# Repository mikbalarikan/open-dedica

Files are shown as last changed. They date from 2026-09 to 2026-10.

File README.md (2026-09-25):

# Open Dedica — open-source DIY espresso machine

A community-built espresso machine: **genuine De'Longhi Dedica EC685 internals** (ULKA pump, 1300 W thermoblock, 51 mm portafilter, OEM valves and tubes) inside a **fully open, 3D-printable chassis**.

The only part of a Dedica you cannot buy as a spare is the group-head housing, which is molded into the case. If that part must be printed anyway, the whole chassis can be an open design.

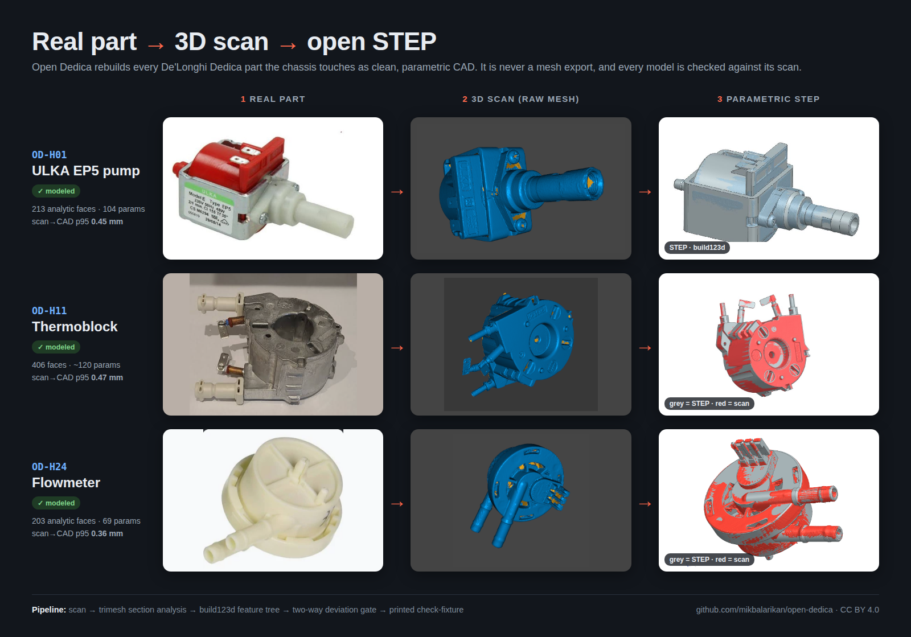
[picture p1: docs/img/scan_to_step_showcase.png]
Real part → 3D scan → open STEP


> ⚠️ **Safety:** this machine runs on mains voltage (230 V / 120 V), heats water to ~125 °C and pressurizes it to 15 bar. Keep the wet side separated from the electric side, keep the 192 °C thermal cutoff (TCO) in circuit, test behind an RCD/GFCI, and never print load-bearing or heat-adjacent parts in PLA.

## How it works

Water path schematic

Tank → flowmeter → ULKA pump → 3-way valve (bypass back to tank) → thermoblock → 3-way connector → group head. The steam branch is phase 2. Details: [docs/WATER_FLOW.md](docs/WATER_FLOW.md).

## Roadmap

| Phase | Goal | Tracking |
|---|---|---|
| **1. 3D scanning** ← *we are here* | Photos + caliper sheet + raw STL for every part the chassis touches | [`phase: scan`](../../issues?q=is%3Aissue+label%3A%22phase%3A+scan%22) |
| 2. STEP library | Rebuild each scan as clean parametric CAD, validate with a printed check-fixture | `phase: step` |
| 3. Chassis | Two-zone printed chassis designed around the STEP assembly; group-head housing first | `phase: chassis` |
| 4. Electronics | OEM PCB (path 1) vs ESP32 + SSR open controller (path 2) | `phase: electronics` |
| 5. Test & release | Pressure / leak / PAT tests, BOM + STEP + STL/3MF + build guide | `phase: test` |

**Scan → STEP progress** (auto-generated from the BOM, details in [docs/STEP_PROGRESS.md](docs/STEP_PROGRESS.md)):

Scan to STEP progress

**Milestone 1:** donor machine torn down, every part catalogued against the BOM, STEP library validated with printed check-fixtures, printed group-head housing bench-tested under pressure.

## How to help

Nobody is pre-assigned — **pick any open issue**. Start with [`good first issue`](../../issues?q=is%3Aissue+is%3Aopen+label%3A%22good+first+issue%22) or the scan requests. Read [CONTRIBUTING.md](CONTRIBUTING.md) first.

## Repository layout

```
docs/          SOURCING_GUIDE.md, BOM.md (generated) + bom.csv (source), PART_NUMBERING.md, WATER_FLOW.md, STEP_PROGRESS.md
tools/         build_bom.py — regenerates docs/BOM.md from docs/bom.csv
scans/         OD-Xnn_<name>/  photos/, calipers.md, raw STL/PLY   (phase 1)
step/          OD-Xnn_<name>.step  clean parametric models          (phase 2)
chassis/       printed chassis CAD + STL/3MF exports                     (phase 3)
electronics/   wiring, pinouts, firmware                                  (phase 4)
```

## Credits & references

- Zack Moss, *Open Source Espresso Machine for Makers*, MEng thesis, University of Sheffield, 2019 — reverse-engineered the EC685.M and proved the concept.
- [CaiJonas Dedica EC685/EC885 mod](https://github.com/CaiJonas/DeLonghi-Dedica-EC885-EC685-modification) — pressure/temperature sensor mod.
- Part codes: De'Longhi EC885.M exploded view (not redistributed here).

This project is not affiliated with or endorsed by De'Longhi. "De'Longhi" and "Dedica" are trademarks of their owners.

## License

Designs and documentation: [CC BY 4.0](LICENSE).

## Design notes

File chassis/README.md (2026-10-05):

# chassis/ — the printed parts and the assembly

Printed chassis CAD and STL/3MF exports (phase 3), designed part by part with the
OGUZ Atölye pipeline (`mikbalarikan/oguz-atolye`); each part's job record sits in
`reports/<part>/` with a README that says how to resume it.

## Goal

Every custom part of the machine that is 3D-printable, designed and reviewed, and
the whole machine delivered as an assembly:

- one parametric build script, STEP (mm, one named solid) and STL/3MF per printed
  part, with its print orientation and material stated;
- the top assembly `OD-000` as a STEP that places every printed part and every OEM
  part of the `step/` library by joints, with the sub-assemblies `OD-H00`, `OD-G00`,
  `OD-W00`, `OD-E00`, `OD-C00`;
- `docs/bom.csv` at `modeled` for every part, `docs/BOM.md` and the progress board
  regenerated, and a build guide (`docs/BUILD_GUIDE.md`) that goes from the BOM to a
  running machine.

`validated` needs a print and a fit check by the Usta; the group head also needs the
bench pressure test (`OD-T01`).

## Order of work

Each part is designed against the scanned OEM parts it touches. A part whose OEM
neighbour is not scanned yet carries that neighbour as an assumption row and is
revisited when the scan lands.

| # | Part | Designed against | Blocked by |
|---|---|---|---|
| 1 | `OD-G01` group head housing | OD-G09, OD-G04, OD-G10 | modeled, RV01 REVISE on REQ-12 alone (brew-load strength, answered only by the OD-T01 bench test), accepted by the Usta as a documented deviation (2026-10-02); every geometric row passes |
| 2 | `OD-C05` group head carrier | OD-G01's rear flange, OD-H11 outlet side | modeled, RV02 approved on assumptions (ASA, K1C); open: drain for the foot trough, counterbore floors to sign, a ≥ 210 mm driver |
| 3 | `OD-C03` pump cradle | OD-H01; sleeve OD-H02 and spring OD-H03 | modeled, approved on assumptions (RV02); calipers: H02 sleeve OD, side-wall gap, tie path |
| 4 | `OD-C04` thermoblock mount | OD-H11 with its NTC/TCO brackets (OD-H17, H19) | modeled, approved on assumptions (RV01); calipers: 10.10 mm air gap, spacer lengths, bracket holes |
| 5 | `OD-C07` valve and flowmeter mount | OD-H22, OD-H24 (OD-H21 sits in the water path, not on the mount) | modeled; RV01 REVISE, two seat gaps accepted by the Usta as deviations |
| 6 | `OD-C06` water tank dock | OD-W03 seat; tank OD-W01/W02 | deferred: the tank stands on the table (the Usta, 2026-10-01); its tubes and the mains cord leave through OD-C11's three Ø12 pass-throughs at y 30 |
| 7 | `OD-C01` base frame / floor plate | the footprints of 2–6; drip tray OD-C21/C22 | modeled, revision B: RV02 approved on assumptions (PLA for now, Kobra Max 3), 38 insert holes; flatness is a bench check; layout assumes the group head vertical, housing rear face 205 mm above the base (awaits the Usta's axis decision); OD-C01 A-12 (feet screwed from below) is superseded by OD-C15 A-02 (screw from above, captive nut); revision B (spec 1.3, build v03, RV02 approved on assumptions) adds the 18 holes for OD-C08, OD-C11, OD-C16 and OD-C09 |
| 8 | `OD-C02` wet/electric bulkhead | OD-C01, the tube runs | modeled, RV01 approved on assumptions (ASA, K1C); M3×12 into the base rail (`OD-F10`) |
| 9 | `OD-C08` electronics bay tray | OD-E01, OD-E02 (path 1) or OD-E51…E58 (path 2) | modeled, RV01 approved on assumptions (PETG, K1C); path 1, the OEM PCB OD-E01 on edge; OD-E02 (front buttons) belongs to OD-C09 |
| 10 | `OD-C09` front panel with button bezel | OD-G01 mouth, OD-E02 buttons, OD-S03 knob (phase 2) | modeled, RV01 approved on assumptions (PLA, Kobra Max 3): 3.0 fascia at z +94 … +97 with return ribs round the brew opening, two floor flanges into four OD-C01 inserts, OD-E02 on two Ø11 bosses (buttons in a column on the left pillar); the locked portafilter swings φ −55 … +10 with ≥ 2.5 to the window edge; the phase-2 steam knob place stays free |
| 11 | `OD-C10`, `OD-C11` top and back panels | OD-C01, OD-C02 | modeled, both RV01 approved on assumptions (PETG, Kobra Max 3); OD-C11 took three builds (spec faults in 1.0 and 1.1, recorded) |
| 12 | `OD-C12`, `OD-C13` side panels; `OD-C16` corner brackets | OD-C01 | modeled, RV01 approved on assumptions (PLA, printed not acrylic): 3.0 plates 385 × 218.8 on the Kobra Max 3 with a 60° lip that locates the lid skirt (0.40 per side); OD-C12 has a 0.9 relief over OD-C07; six 19 × 16 × 16 brackets (three per side), one M3 down into OD-C01 and one insert for the panel screw; the lid now rests on the panel tops (answers OD-C10 F1) |
| 13 | `OD-C14` cable grommets, `OD-C15` feet (TPU) | OD-C01, OD-E06 cord | `OD-C15` modeled, RV01 approved on assumptions: Ø18 × 10 puck, M3×12 from the top into a captive M3 nut; `OD-C14` modeled, RV01 approved on assumptions: two identical PLA halves around the Ø7.0 cord (the Usta's calipers), closed by one `OD-F09` tie inside OD-C11's wall |
| 14 | `OD-T01` group head pressure-test rig | OD-G01, OD-G10 | modeled, v02 (25 mm plate, the Usta's decision on RV01 F1), RV02 approved on assumptions: a closed PLA frame 240 × 160 × 120 that holds OD-G01 mouth down by its four inserts; procedure `OD-T01_TEST_PROCEDURE.md` (100 % infill, watch the screw heads) closes OD-G01 REQ-12 on the bench |
| 15 | `OD-C00` … `OD-000` assemblies | everything above plus the `step/` library | all parts |

**Material for now:** the Usta set PLA for every printed part (2026-10-02); the BOM
keeps each part's service material next to it. PLA softens near 60 °C, so PLA
prints of `OD-G01`, `OD-C02`, `OD-C04` and `OD-C05` (next to the thermoblock and the
group head; OD-C02 stands 13 from the casting) are dry fit checks only: never run hot water or pressure through them, and
run the OD-T01 bench test on an ASA housing.

Machine profiles: Creality K1C (enclosed: ASA, PC) and Anycubic Kobra Max 3 (large
panels: PETG); build volumes to be read into `oguz-atolye/atolye/machines/`.

## Interfaces to OD-C01

Parts that bolt to the base frame fix it with M3 screws into heat-set inserts
(`OD-F01`) in `OD-C01`. Coordinates are in each part's own frame, from its job
record; OD-C01 must carry an insert at each.

| Part | Inserts in OD-C01 (x, z) mm | Hardware |
|---|---|---|
| `OD-C03` pump cradle | (±34, −4), (±34, 37) | 4 × M3 (`OD-F02`), 2 × cable tie (`OD-F09`) |
| `OD-C04` thermoblock mount | (±40, −8), (±40, 26) | 4 × M3 (`OD-F02`); the thermoblock sits on the metal spacers `OD-F07` and `OD-F08` (a Ø3.5 self-tapping screw (`OD-F16`) through each Ø4 bore into the thermoblock, S1 ≈ 22 and S2 ≈ 50 long (OD-C04 A-04)) |
| `OD-C07` valve and flowmeter mount | four Ø3.4 through-holes at (−18, ±21) and (88.5, ±21) in the mount frame; OD-C01 spec 1.1 REQ-10 provides them | 4 × M3 (`OD-F02`) into OD-C01; 2 × M3 insert (`OD-F01`) for OD-H22 |
| `OD-C08` electronics bay tray | flange (88, −222), (106, −222), (88, −78), (106, −78) | 4 × M3×8 (`OD-F02`); 2 × M3×6 (`OD-F11`) for the board into 2 inserts in the tray's standoffs |
| `OD-C11` back panel | flanges (±81, −282), (±95, −282) | 4 × M3×8 (`OD-F02`); 2 inserts in its ledge take OD-C10's rear screws |
| `OD-C10` top panel | none: 2 screws into OD-C02's top-rail inserts, 2 into OD-C11's ledge | 4 × M3×8 (`OD-F02`) |
| `OD-C16` side-panel brackets | (±104.5, −262), (±104.5, −15), (±104.5, +62) | 6 × M3×8 (`OD-F02`) down into OD-C01, 6 more through the panels into the brackets' inserts |
| `OD-C09` front panel | (±85, +77), (±95, +77) | 4 × M3×8 (`OD-F02`); OD-E02 on 2 × M3×18 (`OD-F13`) into 2 inserts in the panel's bosses |
| `OD-C15` feet | none: the four Ø3.4 through-holes at (±110, +90) and (±110, −295) | 4 × M3×12 (`OD-F10`) from the plate top, 4 × M3 nut (`OD-F12`) captive in the feet |

Insert pattern as built into OD-C01 (OD-C01 frame, x and z in mm):

| Part | x | z |
|---|---|---|
| `OD-C05` | ±35 | −40, −60 |
| `OD-C04` | ±40 | −148, −114 |
| `OD-C03` | −4, 37 | −239, −171 |
| `OD-C02` | 65 | −45, −105, −165, −225 |
| `OD-C07` | −113, −71 | −42, −148.5 |
| `OD-C08` | 88, 106 | −222, −78 |
| `OD-C11` | ±81, ±95 | −282 |
| `OD-C16` | ±104.5 | −262, −15, +62 |
| `OD-C09` | ±85, ±95 | +77 |

Revision B's eighteen holes are Ø4.0 through the 6.0 plate like the other twenty, inserts driven from the top (OD-C01 spec 1.3, A-11); RV02 measured each ≥ 10.0 centre to centre from every other hole and ≥ 10.0 from the plate's outline. The four holes at x 65 stay empty: OD-C02's M3×12 pass through them from below into the bulkhead's rail.

Frames for OD-000: OD-C01, OD-C02, OD-C08, OD-C10, OD-C11 and OD-C07's footprint use the machine frame (X right, +Y up, +Z front, plate top y = 0); OD-C05 is in the housing frame (x → X, y → +Z, z → −Y, origin (0, 180.06, 32.0)). Check every insert pattern with calipers before the first print.

OD-000 placements handed over by the part jobs (joint frames; the assembly uses them):

- `OD-C07`: OD-H24 at (0, 0, 10) and OD-H22 at (62, 0, 48) in the mount frame; the mount sits on OD-C01 with mount x → −Z, y → −X, z → +Y, origin (−92, 0, −60) in the OD-C01 frame.
- `OD-C08`, `OD-C10`, `OD-C11`: modelled in the machine frame, placed at the identity. OD-E01 sits on OD-C08 with board x → −Z, y → +Y, z → +X, origin (84, 80, −100). Check assemblies: `reports/<part>/02_STEP_STL/`.
- `OD-C15`: foot frame origin at the centre of its top face, foot z 0 … 10; foot x → X, y → +Z, z → −Y, origins (±110, −6, +90) and (±110, −6, −295). The counter is at y −16. Check assembly: `reports/OD-C15_foot/02_STEP_STL/od_c15_assembly_C1_v01.step`.
- `OD-C12`, `OD-C13`: identity; outer faces at x ±120, z −295 … +90, wall y 0 … 215, lip apex y 218.81.
- `OD-C16` (its frame: block x −19 … 0, y 0 … 16, z ±8): right side translate (117, 0, z_c); left side rotate 180° about Y, then translate (−117, 0, z_c); z_c ∈ {−262, −15, +62}.
- `OD-C14` half: identity; the second half is the same solid rotated 180° about the line through (x 95, y 30) along Z; flange on OD-C11's outer face (z −304 … −302).
- `OD-C09`: identity. OD-E02 on it: board x → −Y, y → −X, z → −Z, origin (−99.0, 140.0, 69.35); its two M3×18 from the board's back into the bosses. OD-T01 is a bench fixture, not in OD-000.
- `OD-G01`: the group head stands with its axis vertical and the mouth down (the spec §2 sentence saying +Z is horizontal is being corrected in spec 1.4).

Keep-outs for later parts:

- `OD-C15` (spec A-09): a Ø8 × 2.0 cylinder above each foot hole on the plate top (y 0 … 2.0) holds the screw head. OD-C11's wall foot clears it by 0.0 (touching, no overlap); OD-C12, OD-C13 and OD-C16 leave it free (side REQ-07); OD-C06 must too.
- `OD-C08` occupies x 73 … 112, z −230 … −70, y 0 … 92 (with the board, to x ≈ 109.3).
- Front corners: OD-C09's wall ends at x ±116 and the side panels at z +90, so about 4 stays open at each front R 10 corner, closed above by OD-C10's skirt; a small corner cap (or OD-C16 at the front corners) can close it. OD-E02 reaches x −115.17, 1.83 inside the left panel. OD-C10's front skirt rests on OD-C09's top edge (y 215), no screws at the front.
- OD-C09 keeps free: the phase-2 steam knob place (Ø32 about x +95.5, y 140, z +60 … +93.8) and the drip tray slot x ±74.8, y 0 … 49.8, z −15 … +120.
- Assembly order (OD-C09 A-14): screw OD-C09 to the plate before OD-E02 goes on; drive the board's two screws from behind with the lid off.
- Rear corners: a ≈ 4 × 4 opening stays between each side panel's end and OD-C11's wall over the plate's corner, closed above by the lid; a small printed cap can close it later.
- The cord grommet's tie head points up inside OD-C11's wall: nothing within 0.5 of it.

"Approved on assumptions" (`APPROVED_ASSUMPTION_CONDITIONAL`) means every gate
passes on scan-derived values that the Usta has not confirmed with calipers yet;
the BOM shows such parts as `modeled`, and `validated` still needs the print and
fit check.

## Files

```
chassis/
  OD-Cnn_<short_name>.step  .stl  .3mf     one per printed part (OD-G01 too)
  OD-000_open_dedica_assembly.step         the top assembly, sub-assemblies inside
  src/OD-Xnn_<short_name>/build_*.py       parametric build and check scripts
  reports/OD-Xnn_<short_name>/             the job record of each part
```

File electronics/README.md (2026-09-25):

# electronics/

Wiring diagrams, OEM PCB pinouts, open-controller firmware (phase 4).

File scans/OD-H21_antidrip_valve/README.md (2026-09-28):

# OD-H21_antidrip_valve — Anti-drip valve

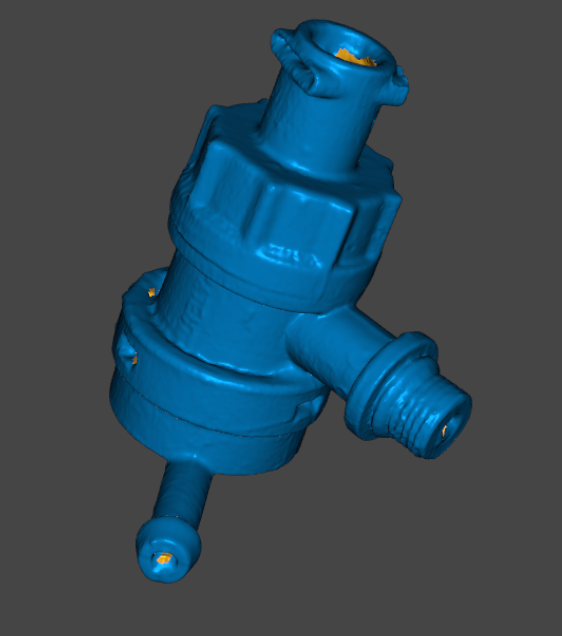
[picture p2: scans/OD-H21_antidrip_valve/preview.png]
scan preview


| | |
|---|---|
| Part | `OD-H21` (ref 39, OEM 7313260161) — see [docs/BOM.md](../../docs/BOM.md) |
| Mesh | `OD-H21_antidrip_valve_raw.stl` — binary STL, **mm**, full resolution, not watertight |
| Scanner | CR-Scan Raptor, 3 merged scan session(s) |
| Date | 2026-09-25 (scan), 2026-09-28 (STEP) |

STEP rebuild: [`step/OD-H21_antidrip_valve.step`](../../step/OD-H21_antidrip_valve.step) — report in [`step/reports/OD-H21_antidrip_valve/`](../../step/reports/OD-H21_antidrip_valve/). Tracked in #41.

## Still missing for this scan
- [ ] `photos/` — own photos with a ruler (the RE run used catalogue images, which we can't publish)
- [ ] `calipers.md` — interface dimensions (the mesh is for the envelope only; calipers win on every fit)

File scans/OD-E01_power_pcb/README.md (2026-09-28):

# OD-E01_power_pcb — Power PCB

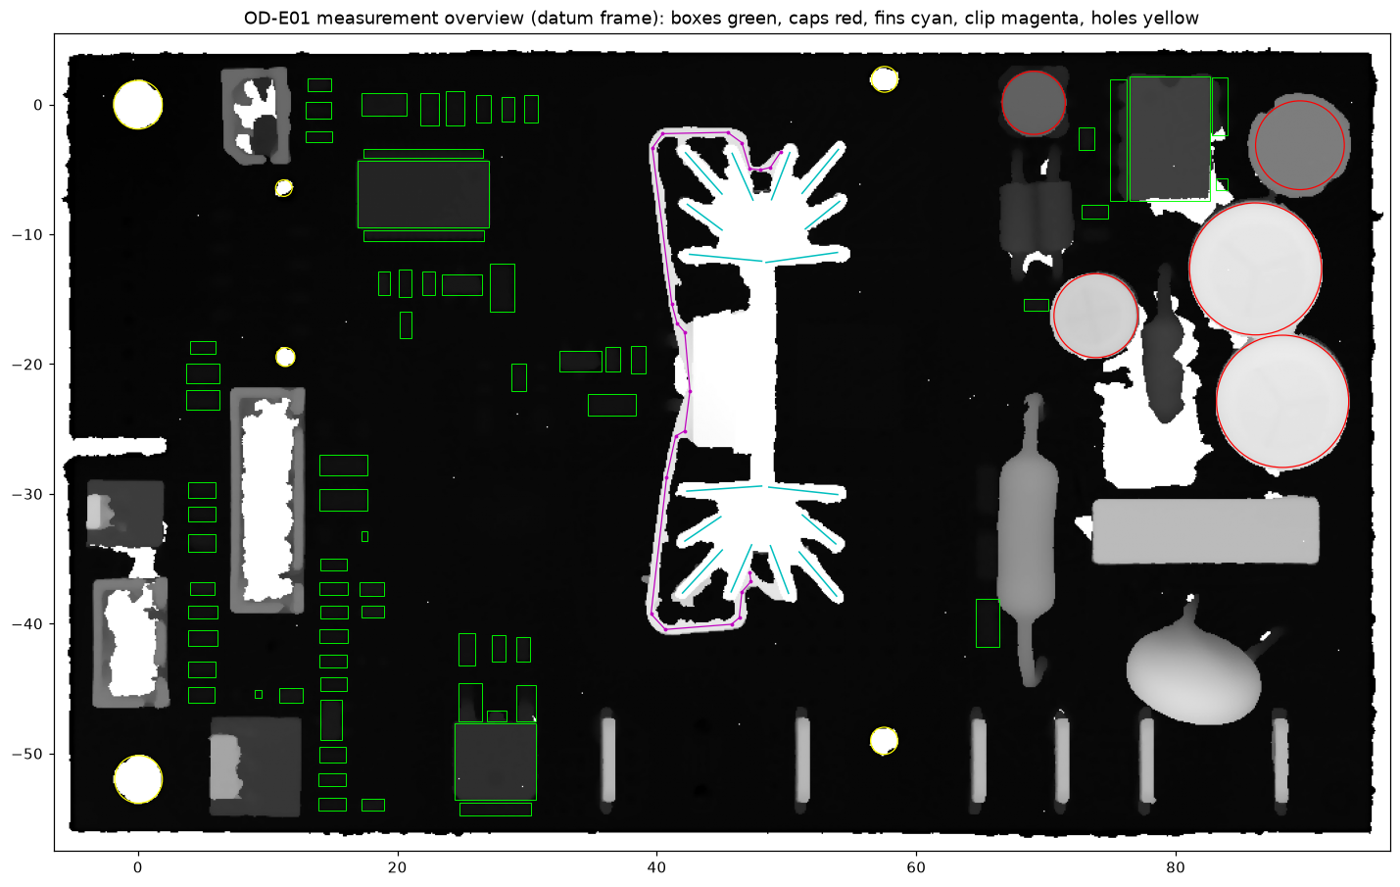
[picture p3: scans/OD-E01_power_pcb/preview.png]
scan preview


| | |
|---|---|
| Part | `OD-E01` (ref 59, OEM AS00002829) — see [docs/BOM.md](../../docs/BOM.md) |
| Mesh | `OD-E01_power_pcb_raw.stl` — binary STL, **mm**, full resolution, not watertight |
| Scanner | CR-Scan Raptor, 1 merged scan session(s) |
| Date | 2026-09-28 |

STEP rebuild: [`step/OD-E01_power_pcb.step`](../../step/OD-E01_power_pcb.step) — report in [`step/reports/OD-E01_power_pcb/`](../../step/reports/OD-E01_power_pcb/). Tracked in #33.

## Still missing for this scan
- [ ] `photos/` — own photos with a ruler (the RE run used catalogue images, which we can't publish)
- [ ] `calipers.md` — interface dimensions (the mesh is for the envelope only; calipers win on every fit)

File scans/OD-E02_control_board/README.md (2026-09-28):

# OD-E02_control_board — Control button board

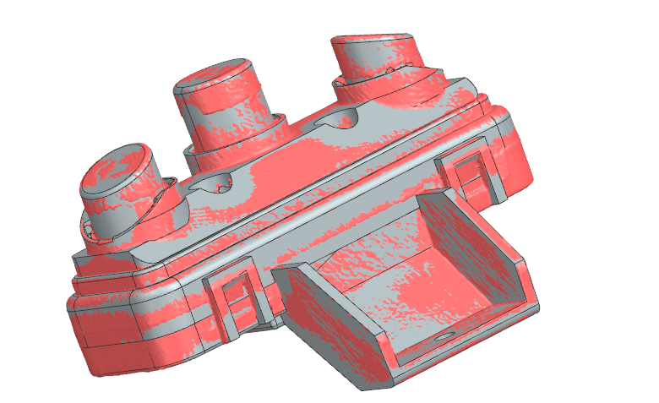
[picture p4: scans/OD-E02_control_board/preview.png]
scan preview


| | |
|---|---|
| Part | `OD-E02` (ref 15, OEM 7313285189) — see [docs/BOM.md](../../docs/BOM.md) |
| Mesh | `OD-E02_control_board_raw.stl` — binary STL, **mm**, full resolution, not watertight |
| Scanner | CR-Scan Raptor, 2 merged scan session(s) |
| Date | 2026-09-28 |

STEP rebuild: [`step/OD-E02_control_board.step`](../../step/OD-E02_control_board.step) — report in [`step/reports/OD-E02_control_board/`](../../step/reports/OD-E02_control_board/). Tracked in #34.

## Still missing for this scan
- [ ] `photos/` — own photos with a ruler (the RE run used catalogue images, which we can't publish)
- [ ] `calipers.md` — interface dimensions (the mesh is for the envelope only; calipers win on every fit)

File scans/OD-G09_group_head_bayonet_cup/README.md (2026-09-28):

# OD-G09_group_head_bayonet_cup — OEM group head bayonet cup

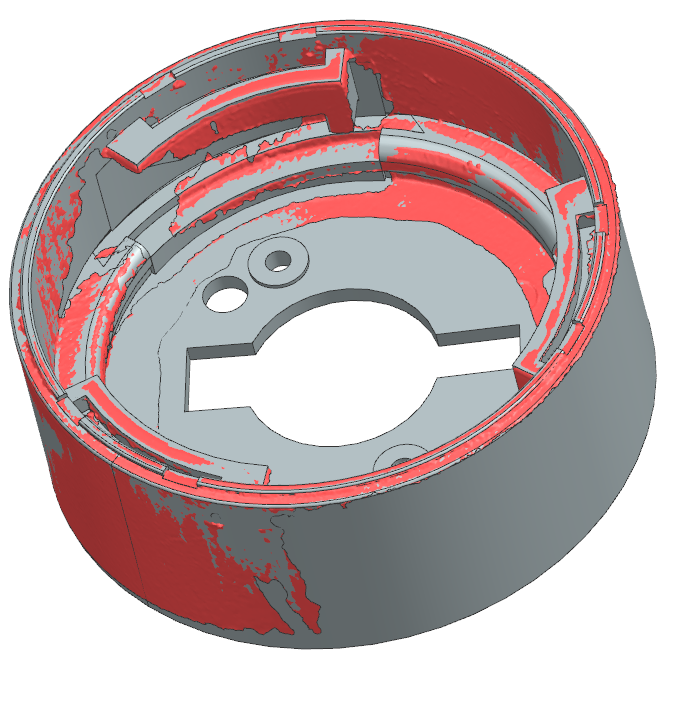
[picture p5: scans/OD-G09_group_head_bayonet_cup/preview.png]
scan preview


| | |
|---|---|
| Part | `OD-G09` (ref —, OEM — (molded into the OEM case)) — see [docs/BOM.md](../../docs/BOM.md) |
| Mesh | `OD-G09_group_head_bayonet_cup_raw.stl` — binary STL, **mm**, full resolution, not watertight |
| Scanner | CR-Scan Raptor, 1 merged scan session(s) |
| Photos | [`photos/`](photos/) — 2 own photos (no scale reference) |
| Date | 2026-09-28 |

STEP rebuild: [`step/OD-G09_group_head_bayonet_cup.step`](../../step/OD-G09_group_head_bayonet_cup.step) — report in [`step/reports/OD-G09_group_head_bayonet_cup/`](../../step/reports/OD-G09_group_head_bayonet_cup/). Tracked in #38.

## Still missing for this scan
- [ ] `calipers.md` — interface dimensions (the mesh is for the envelope only; calipers win on every fit)

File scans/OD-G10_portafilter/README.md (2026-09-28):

# OD-G10_portafilter — Portafilter 51 mm

scan preview

| | |
|---|---|
| Part | `OD-G10` (ref 06, OEM AS00002706) — see [docs/BOM.md](../../docs/BOM.md) |
| Mesh | `OD-G10_portafilter_raw.stl` — binary STL, **mm**, full resolution, not watertight |
| Scanner | CR-Scan Raptor, 3 merged scan session(s) |
| Photos | [`photos/`](photos/) — 2 own photos (no scale reference) |
| Date | 2026-09-28 |

STEP rebuild: [`step/OD-G10_portafilter.step`](../../step/OD-G10_portafilter.step) — report in [`step/reports/OD-G10_portafilter/`](../../step/reports/OD-G10_portafilter/). Tracked in #39.

## Still missing for this scan
- [ ] `calipers.md` — interface dimensions (the mesh is for the envelope only; calipers win on every fit)

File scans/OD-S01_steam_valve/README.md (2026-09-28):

# OD-S01_steam_valve — Steam valve assembly

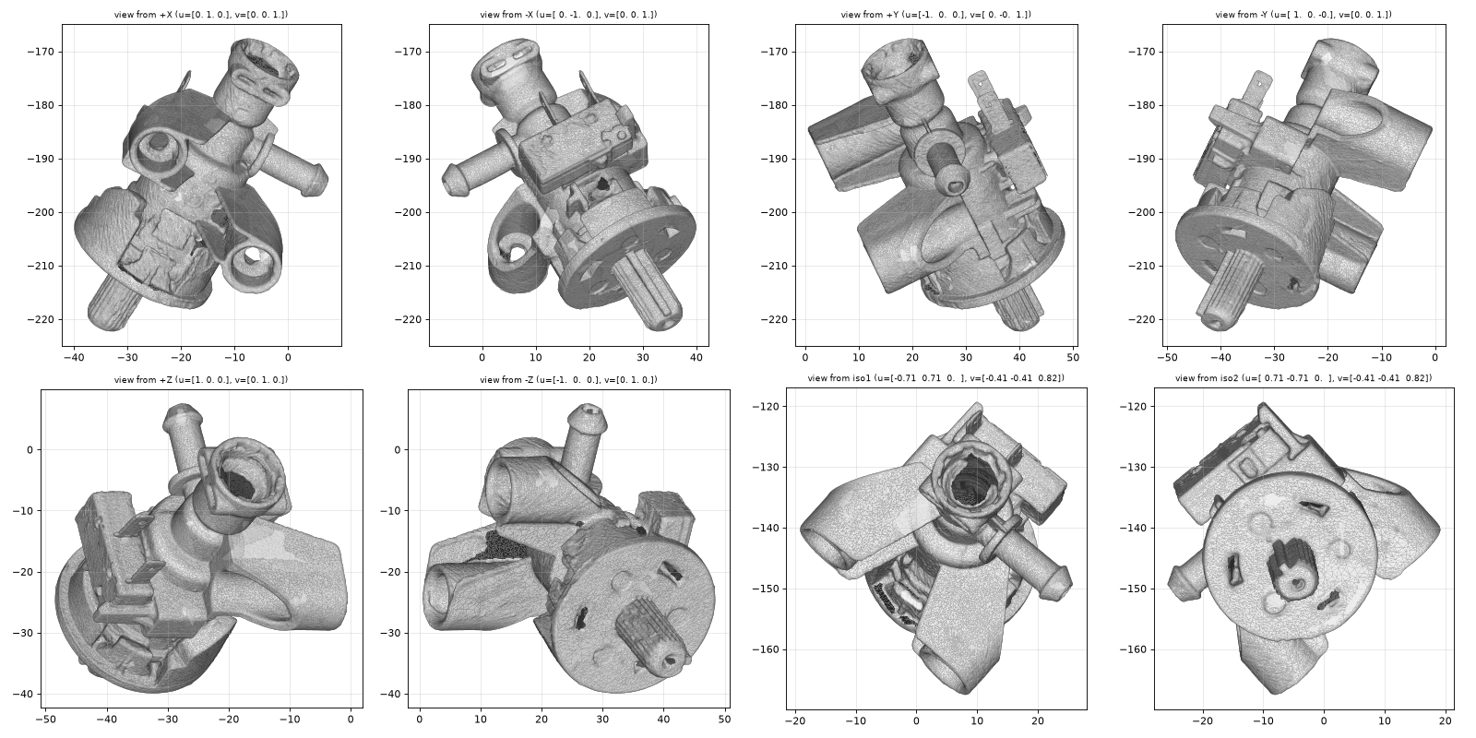
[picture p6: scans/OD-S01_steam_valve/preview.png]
scan preview


| | |
|---|---|
| Part | `OD-S01` (ref 17, OEM AS00002707) — see [docs/BOM.md](../../docs/BOM.md) |
| Mesh | `OD-S01_steam_valve_raw.stl` — binary STL, **mm**, full resolution, not watertight |
| Scanner | CR-Scan Raptor, 3 merged scan session(s) |
| Date | 2026-09-28 |

STEP rebuild: [`step/OD-S01_steam_valve.step`](../../step/OD-S01_steam_valve.step) — report in [`step/reports/OD-S01_steam_valve/`](../../step/reports/OD-S01_steam_valve/). Tracked in #35.

## Still missing for this scan
- [ ] `photos/` — own photos with a ruler (the RE run used catalogue images, which we can't publish)
- [ ] `calipers.md` — interface dimensions (the mesh is for the envelope only; calipers win on every fit)

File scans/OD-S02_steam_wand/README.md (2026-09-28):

# OD-S02_steam_wand — Steam wand (steam hose assembly + nozzle)

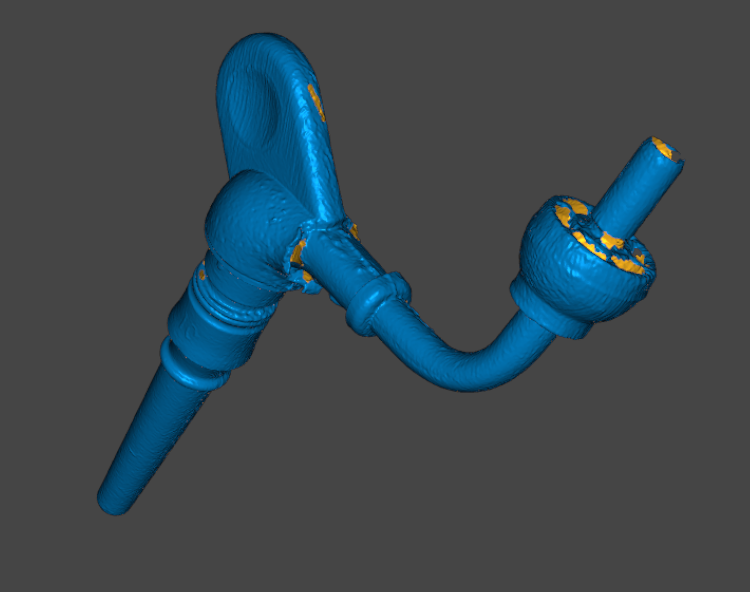
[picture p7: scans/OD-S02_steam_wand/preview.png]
scan preview


| | |
|---|---|
| Part | `OD-S02` (ref 10 + 77, OEM AS00002705 + AS00002710) — see [docs/BOM.md](../../docs/BOM.md) |
| Mesh | `OD-S02_steam_wand_raw.stl` — binary STL, **mm**, full resolution, not watertight |
| Scanner | CR-Scan Raptor, 2 merged scan session(s) |
| Photos | [`photos/`](photos/) — 2 own photos (no scale reference) |
| Date | 2026-09-28 |

STEP rebuild: [`step/OD-S02_steam_wand.step`](../../step/OD-S02_steam_wand.step) — report in [`step/reports/OD-S02_steam_wand/`](../../step/reports/OD-S02_steam_wand/). Tracked in #36.

## Still missing for this scan
- [ ] `calipers.md` — interface dimensions (the mesh is for the envelope only; calipers win on every fit)

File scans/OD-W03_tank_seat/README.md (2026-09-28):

# OD-W03_tank_seat — Tray gasket (water tank seat)

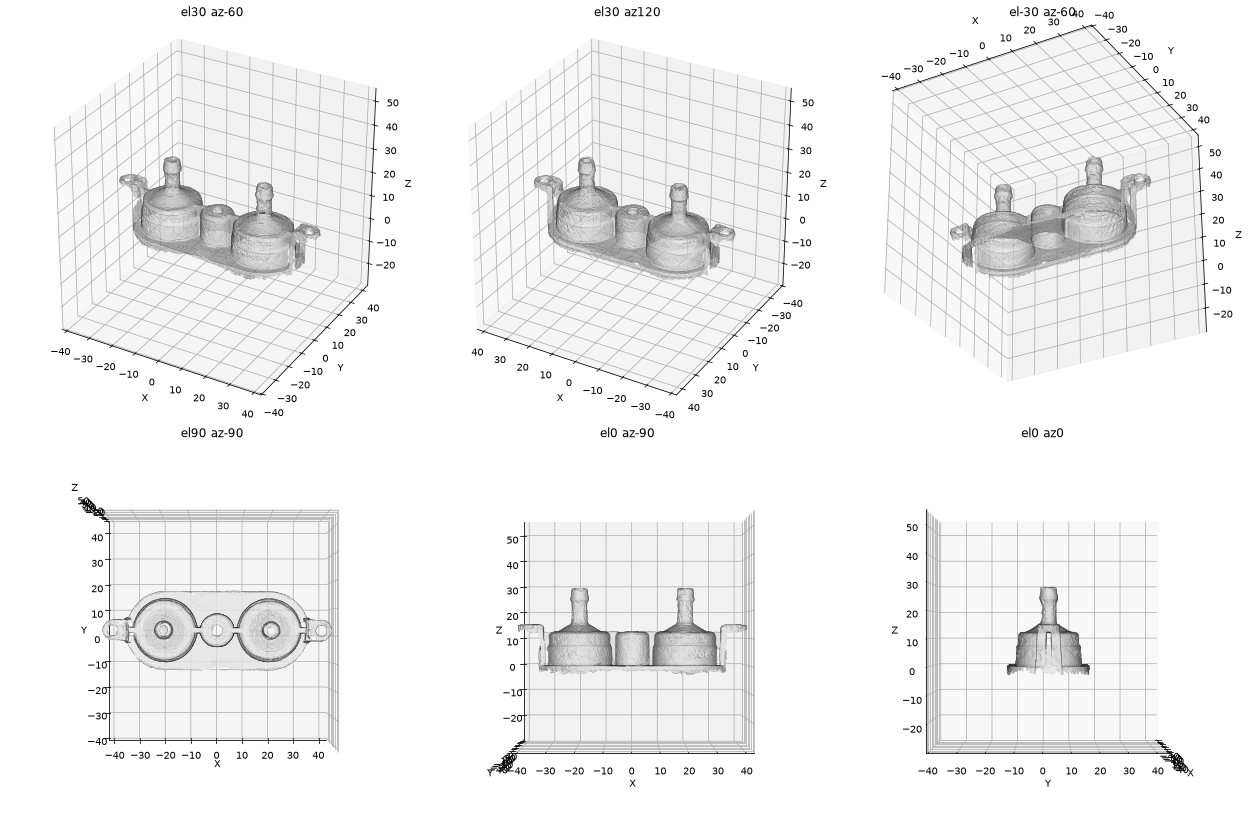
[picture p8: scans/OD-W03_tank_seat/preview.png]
scan preview


| | |
|---|---|
| Part | `OD-W03` (ref 30, OEM 5313236391) — see [docs/BOM.md](../../docs/BOM.md) |
| Mesh | `OD-W03_tank_seat_raw.stl` — binary STL, **mm**, full resolution, not watertight |
| Scanner | CR-Scan Raptor, 1 merged scan session(s) |
| Date | 2026-09-28 |

STEP rebuild: [`step/OD-W03_tank_seat.step`](../../step/OD-W03_tank_seat.step) — report in [`step/reports/OD-W03_tank_seat/`](../../step/reports/OD-W03_tank_seat/). Tracked in #37.

## Still missing for this scan
- [ ] `photos/` — own photos with a ruler (the RE run used catalogue images, which we can't publish)
- [ ] `calipers.md` — interface dimensions (the mesh is for the envelope only; calipers win on every fit)

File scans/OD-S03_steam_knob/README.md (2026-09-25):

# OD-S03_steam_knob — Steam knob

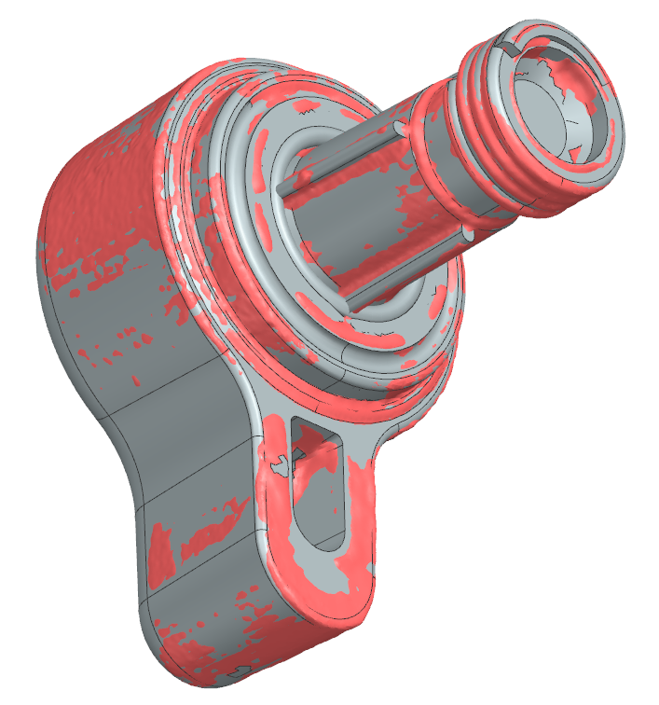
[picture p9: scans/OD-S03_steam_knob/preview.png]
scan preview


| | |
|---|---|
| Part | `OD-S03` (ref 13, OEM 7313285479) — see [docs/BOM.md](../../docs/BOM.md) |
| Mesh | `OD-S03_steam_knob_raw.stl` — binary STL, **mm**, 363 988 triangles, full resolution, not watertight |
| Bounding box | 31.3 × 39.2 × 37.4 mm (scanner frame, not aligned to part axes) |
| Scanner | Creality CR-Scan Raptor, laser mode, 2 merged scan sessions |
| Date | 2026-09-25 |

STEP rebuild: [`step/OD-S03_steam_knob.step`](../../step/OD-S03_steam_knob.step) — report in [`step/reports/OD-S03_steam_knob/`](../../step/reports/OD-S03_steam_knob/).

## Known mesh defects
- Chrome surfaces: a loose "skin flap" inside the cap wall at a scan-hole edge (the real wall is intact).
- Lever-pocket floor and the deep sleeve bore (with internal splines) not reached.

## Still missing for this scan
- [ ] `photos/` — own photos with a ruler (the RE run used catalogue images, which we can't publish)
- [ ] `calipers.md` — interface dimensions

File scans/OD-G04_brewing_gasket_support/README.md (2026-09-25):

# OD-G04_brewing_gasket_support — Brewing gasket support

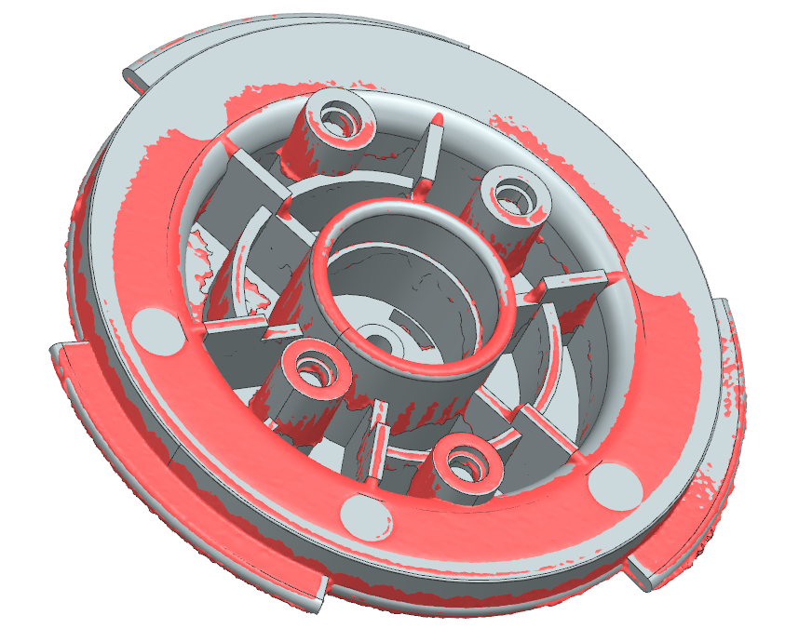
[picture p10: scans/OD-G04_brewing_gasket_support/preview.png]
scan preview


| | |
|---|---|
| Part | `OD-G04` (ref 48, OEM AS00005377) — see [docs/BOM.md](../../docs/BOM.md) |
| Mesh | `OD-G04_brewing_gasket_support_raw.stl` — binary STL, **mm**, 484 578 triangles, full resolution, not watertight |
| Bounding box | 68.0 × 50.8 × 47.2 mm (scanner frame, not aligned to part axes) |
| Scanner | Creality CR-Scan Raptor, laser mode, 0.1 mm fusion voxel, 2 merged scan sessions |
| Date | 2026-09-25 |

STEP rebuild: [`step/OD-G04_brewing_gasket_support.step`](../../step/OD-G04_brewing_gasket_support.step) — report in [`step/reports/OD-G04_brewing_gasket_support/`](../../step/reports/OD-G04_brewing_gasket_support/).

## Known mesh defects
- Front cavity / plate underside scanned in one sector only; hub interior and the outer-wall gap not reached.
- Thin walls (2.3–2.6 mm) — both skins are close together, so automatic registration can snap to the wrong side.

## Still missing for this scan
- [ ] `photos/` — own photos of front, back and side with a ruler (the RE run used catalogue images, which we can't publish)
- [ ] `calipers.md` — interface dimensions

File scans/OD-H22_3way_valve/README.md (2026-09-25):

# OD-H22_3way_valve — 3-way valve

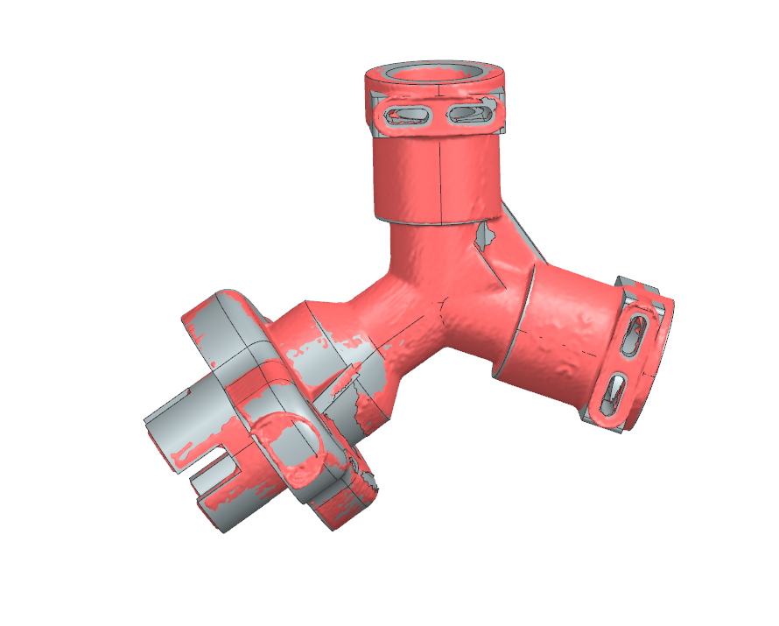
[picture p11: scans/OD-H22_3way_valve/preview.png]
scan preview


| | |
|---|---|
| Part | `OD-H22` (ref 43, OEM AS00004266) — see [docs/BOM.md](../../docs/BOM.md) |
| Mesh | `OD-H22_3way_valve_raw.stl` — binary STL, **mm**, 495 881 triangles, full resolution, not watertight |
| Bounding box | 40.0 × 42.0 × 48.1 mm (scanner frame, not aligned to part axes) |
| Scanner | Creality CR-Scan Raptor, laser mode, 0.1 mm fusion voxel, 2 merged scan sessions |
| Photos | [`photos/photo_4.png`](photos/photo_4.png) — own photo, no scale reference (photos 1–3 of the RE run were seller catalogue images and are not redistributed) |
| Date | 2026-09-25 |

STEP rebuild: [`step/OD-H22_3way_valve.step`](../../step/OD-H22_3way_valve.step) — report in [`step/reports/OD-H22_3way_valve/`](../../step/reports/OD-H22_3way_valve/).

## Known mesh defects
- The +X ear tip of this specimen is damaged / torn (jagged outline) — or carries a small pip (photo 4); unresolved.
- Stray scan material bridges the mouth of the +X ear screw hole (the hole is open through in the photos).
- Port bores and the lower drive-tube bore are unscanned (28 open boundary loops).

## Still missing for this scan
- [ ] `calipers.md` — interface dimensions (ear-hole spacing and Ø, port OD, drive-tube OD, flange thickness)
- [ ] Photos with a ruler / scale reference

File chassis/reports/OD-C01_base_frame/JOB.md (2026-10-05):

---
schema: oguz-job-v1
job_id: "20260930-od-c01-base-frame"
code: ODC01
milestone: M1
title: "Open Dedica OD-C01 printed base frame"
lane: CAD
state: J5_DELIVER
blocked_on: null
next_action: "J5: the Usta prints the plate (PLA, Kobra Max 3) and checks every insert pattern with calipers; REQ-09 flatness answers at the first print; RV02 F2/F5 noted"
data_class: PUBLIC
size: M
process: [FDM]
gate_sections: [U, D, E]
spec: "00_Spec/DESIGN_SPEC.md"
spec_version: "1.3"
workspace: "${OGUZ_JOBS}/20260930-od-c01-base-frame"
delivery: "${OGUZ_DELIVERY}/20260930-od-c01-base-frame"
artifacts: "${OGUZ_ARTIFACTS}/20260930-od-c01-base-frame"
repo_commit: d7ea010502a30dd025c5123992847da1b15f3ee3
active_target: od_c01_frame_v03
revision: B
open_assumptions: [A-01, A-02, A-03, A-04, A-05, A-06, A-07, A-08, A-09, A-10, A-11, A-12, A-13, A-14, A-15, A-16, A-17, A-18, A-19, A-20]
attempts: {build: 1, export: 0, tool: 0}
caps: {build: 2, export: 2, tool: 2, fix_cycles: 3}
reviews:
  - {id: RV01, target: od_c01_frame_v02, verdict: APPROVED_ASSUMPTION_CONDITIONAL, blockers: 0, date: "2026-09-30"}
  - {id: RV02, target: od_c01_frame_v03, verdict: APPROVED_ASSUMPTION_CONDITIONAL, blockers: 0, date: "2026-10-05"}
usta_gates:
  - {gate: spec_ratified, outcome: "1.0", date: "2026-09-30"}
  - {gate: concept_picked, outcome: C1, date: "2026-09-30"}
  - {gate: spec_ratified, outcome: "1.1", date: "2026-09-30"}
  - {gate: spec_ratified, outcome: "1.2", date: "2026-09-30"}
  - {gate: question_answered, outcome: confirmed, date: "2026-09-30"}
  - {gate: spec_ratified, outcome: "1.3", date: "2026-10-05"}
  - {gate: halt_decision, outcome: another_round, date: "2026-10-05"}
deliverables: [STEP, STL, "3MF"]
physical_outcome: n/a
client_source_delete_after: null
---

<!--
JOB.md is the job's state and its resume point (PLAYBOOK §5). Only
tools/jobstate.py writes it (D-032), at the end of every orchestrator turn. Keep the
whole file under 5,000 tokens so it survives compaction whole: no narrative, no
logs, no measurements (those live in REPORT, VERDICT, and EVENTS.jsonl).

The SessionStart hook prints job_id, code, lane, data_class, state, blocked_on,
active_target, attempts against caps, next_action, open_assumptions, and the notes
section below.

Counters: build counts the designer packages sent for the active target (in the RE
lane, the re-drafter packages for the active feature), a RETURNED submission
included; export and tool count retries in the current step. Counters reset only
when a new target or RE feature starts, or when the Usta orders another round.
Reaching a cap is a halt (PLAYBOOK rule 9). fix_cycles goes into the designer's brief
and bounds its own fix-and-re-measure loop.
-->

## Notes for a resuming session

## Close summary

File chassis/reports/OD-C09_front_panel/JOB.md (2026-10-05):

---
schema: oguz-job-v1
job_id: "20261002-od-c09-front-panel"
code: ODC09
milestone: M1
title: "Open Dedica OD-C09 printed front panel with button bezel"
lane: CAD
state: J5_DELIVER
blocked_on: null
next_action: "J5: the Usta merges the open-dedica PR; then J6 close with PHYSICAL_OUTCOME pending the first print (REQ-08 stiffness, A-04 button feel, A-05 lock angle)"
data_class: PUBLIC
size: M
process: [FDM]
gate_sections: [U, D, J, E]
spec: "00_Spec/DESIGN_SPEC.md"
spec_version: "1.1"
workspace: "${OGUZ_JOBS}/20261002-od-c09-front-panel"
delivery: "${OGUZ_DELIVERY}/20261002-od-c09-front-panel"
artifacts: "${OGUZ_ARTIFACTS}/20261002-od-c09-front-panel"
repo_commit: "10929db1408d89144bd4af9cad971440427933d0"
active_target: od_c09_front_v01
revision: A
open_assumptions: [A-01, A-02, A-03, A-04, A-05, A-06, A-07, A-08, A-09, A-10, A-11, A-12, A-13, A-14]
attempts: {build: 1, export: 0, tool: 0}
caps: {build: 2, export: 2, tool: 2, fix_cycles: 3}
reviews:
  - {id: RV01, target: od_c09_front_v01, verdict: APPROVED_ASSUMPTION_CONDITIONAL, blockers: 0, date: "2026-10-03"}
usta_gates:
  - {gate: spec_ratified, outcome: "1.0", date: "2026-10-02"}
  - {gate: concept_picked, outcome: C1, date: "2026-10-02"}
  - {gate: spec_ratified, outcome: "1.1", date: "2026-10-02"}
deliverables: [STEP, STL, "3MF", scripts, REPORT]
physical_outcome: n/a
client_source_delete_after: null
---

<!--
JOB.md is the job's state and its resume point (PLAYBOOK §5). Only
tools/jobstate.py writes it (D-032), at the end of every orchestrator turn. Keep the
whole file under 5,000 tokens so it survives compaction whole: no narrative, no
logs, no measurements (those live in REPORT, VERDICT, and EVENTS.jsonl).

The SessionStart hook prints job_id, code, lane, data_class, state, blocked_on,
active_target, attempts against caps, next_action, open_assumptions, and the notes
section below.

Counters: build counts the designer packages sent for the active target (in the RE
lane, the re-drafter packages for the active feature), a RETURNED submission
included; export and tool count retries in the current step. Counters reset only
when a new target or RE feature starts, or when the Usta orders another round.
Reaching a cap is a halt (PLAYBOOK rule 9). fix_cycles goes into the designer's brief
and bounds its own fix-and-re-measure loop.
-->

## Notes for a resuming session

## Close summary

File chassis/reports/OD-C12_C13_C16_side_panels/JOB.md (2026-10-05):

---
schema: oguz-job-v1
job_id: "20261002-od-c12-c13-c16-side-panels"
code: ODC12
milestone: M1
title: "Open Dedica OD-C12/OD-C13 printed side panels and OD-C16 corner brackets"
lane: CAD
state: J5_DELIVER
blocked_on: null
next_action: "The Usta merges open-dedica PR #51; then J6 close with PHYSICAL_OUTCOME pending the first prints"
data_class: PUBLIC
size: M
process: [FDM]
gate_sections: [U, D, J, E]
spec: "00_Spec/DESIGN_SPEC.md"
spec_version: "1.2"
workspace: "${OGUZ_JOBS}/20261002-od-c12-c13-c16-side-panels"
delivery: "${OGUZ_DELIVERY}/20261002-od-c12-c13-c16-side-panels"
artifacts: "${OGUZ_ARTIFACTS}/20261002-od-c12-c13-c16-side-panels"
repo_commit: "10929db1408d89144bd4af9cad971440427933d0"
active_target: od_side_panels_v01
revision: A
open_assumptions: [A-01, A-02, A-03, A-04, A-05, A-06, A-07, A-08, A-09, A-10, A-11, A-12, A-13, A-14, A-15]
attempts: {build: 1, export: 0, tool: 0}
caps: {build: 2, export: 2, tool: 2, fix_cycles: 3}
reviews:
  - {id: RV01, target: od_side_panels_v01, verdict: APPROVED_ASSUMPTION_CONDITIONAL, blockers: 0, date: "2026-10-03"}
usta_gates:
  - {gate: spec_ratified, outcome: "1.0", date: "2026-10-02"}
  - {gate: concept_picked, outcome: C1, date: "2026-10-02"}
  - {gate: spec_ratified, outcome: "1.1", date: "2026-10-02"}
  - {gate: spec_ratified, outcome: "1.2", date: "2026-10-03"}
deliverables: [STEP, STL, "3MF", scripts, REPORT]
physical_outcome: n/a
client_source_delete_after: null
---

<!--
JOB.md is the job's state and its resume point (PLAYBOOK §5). Only
tools/jobstate.py writes it (D-032), at the end of every orchestrator turn. Keep the
whole file under 5,000 tokens so it survives compaction whole: no narrative, no
logs, no measurements (those live in REPORT, VERDICT, and EVENTS.jsonl).

The SessionStart hook prints job_id, code, lane, data_class, state, blocked_on,
active_target, attempts against caps, next_action, open_assumptions, and the notes
section below.

Counters: build counts the designer packages sent for the active target (in the RE
lane, the re-drafter packages for the active feature), a RETURNED submission
included; export and tool count retries in the current step. Counters reset only
when a new target or RE feature starts, or when the Usta orders another round.
Reaching a cap is a halt (PLAYBOOK rule 9). fix_cycles goes into the designer's brief
and bounds its own fix-and-re-measure loop.
-->

## Notes for a resuming session

Cloud container job (2026-10-02): the record is mirrored to open-dedica/chassis/reports/ (OD-C14_cord_grommet, OD-C12_C13_C16_side_panels) after every stage; recreate the workspace from there (its README). Env: source an env file setting the four OGUZ_* variables before every tools call. Specs rest on the Usta's answer of 2026-10-02 22:58 UTC (printed panels, PLA for now, cord 7 mm) and the standing instruction; explicit confirmation of §5/§6 pending. Shared files (bom.csv, BOM.md, progress board, chassis/README.md, OD-000, OD-C01 inserts, HANDOVER) belong to the OD-G01 thread; notes in the project folder chassis-C12-C16/integration_notes.md. The container restarted twice; a lost package is re-run as the same attempt with a note event.

## Close summary

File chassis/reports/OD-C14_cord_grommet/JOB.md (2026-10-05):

---
schema: oguz-job-v1
job_id: "20261002-od-c14-cord-grommet"
code: ODC14
milestone: M1
title: "Open Dedica OD-C14 printed cord grommet"
lane: CAD
state: J5_DELIVER
blocked_on: null
next_action: "The Usta merges open-dedica PR #51; then J6 close with PHYSICAL_OUTCOME pending the first prints"
data_class: PUBLIC
size: S
process: [FDM]
gate_sections: [U, D, J, E]
spec: "00_Spec/DESIGN_SPEC.md"
spec_version: "1.2"
workspace: "${OGUZ_JOBS}/20261002-od-c14-cord-grommet"
delivery: "${OGUZ_DELIVERY}/20261002-od-c14-cord-grommet"
artifacts: "${OGUZ_ARTIFACTS}/20261002-od-c14-cord-grommet"
repo_commit: "10929db1408d89144bd4af9cad971440427933d0"
active_target: od_c14_grommet_v01
revision: A
open_assumptions: [A-01, A-02, A-03, A-04, A-05, A-06, A-07, A-08]
attempts: {build: 1, export: 0, tool: 0}
caps: {build: 2, export: 2, tool: 2, fix_cycles: 3}
reviews:
  - {id: RV01, target: od_c14_grommet_v01, verdict: APPROVED_ASSUMPTION_CONDITIONAL, blockers: 0, date: "2026-10-02"}
usta_gates:
  - {gate: spec_ratified, outcome: "1.0", date: "2026-10-02"}
  - {gate: concept_picked, outcome: C1, date: "2026-10-02"}
  - {gate: spec_ratified, outcome: "1.1", date: "2026-10-02"}
  - {gate: spec_ratified, outcome: "1.2", date: "2026-10-02"}
deliverables: [STEP, STL, "3MF", scripts, REPORT]
physical_outcome: n/a
client_source_delete_after: null
---

<!--
JOB.md is the job's state and its resume point (PLAYBOOK §5). Only
tools/jobstate.py writes it (D-032), at the end of every orchestrator turn. Keep the
whole file under 5,000 tokens so it survives compaction whole: no narrative, no
logs, no measurements (those live in REPORT, VERDICT, and EVENTS.jsonl).

The SessionStart hook prints job_id, code, lane, data_class, state, blocked_on,
active_target, attempts against caps, next_action, open_assumptions, and the notes
section below.

Counters: build counts the designer packages sent for the active target (in the RE
lane, the re-drafter packages for the active feature), a RETURNED submission
included; export and tool count retries in the current step. Counters reset only
when a new target or RE feature starts, or when the Usta orders another round.
Reaching a cap is a halt (PLAYBOOK rule 9). fix_cycles goes into the designer's brief
and bounds its own fix-and-re-measure loop.
-->

## Notes for a resuming session

Cloud container job (2026-10-02): the record is mirrored to open-dedica/chassis/reports/ (OD-C14_cord_grommet, OD-C12_C13_C16_side_panels) after every stage; recreate the workspace from there (its README). Env: source an env file setting the four OGUZ_* variables before every tools call. Specs rest on the Usta's answer of 2026-10-02 22:58 UTC (printed panels, PLA for now, cord 7 mm) and the standing instruction; explicit confirmation of §5/§6 pending. Shared files (bom.csv, BOM.md, progress board, chassis/README.md, OD-000, OD-C01 inserts, HANDOVER) belong to the OD-G01 thread; notes in the project folder chassis-C12-C16/integration_notes.md. The container restarted twice; a lost package is re-run as the same attempt with a note event.

## Close summary

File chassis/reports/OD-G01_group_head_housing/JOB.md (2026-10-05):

---
schema: oguz-job-v1
job_id: "20260930-od-g01-group-head-housing"
code: ODG01
milestone: M1
title: "Open Dedica OD-G01 printed group head housing"
lane: CAD
state: J5_DELIVER
blocked_on: null
next_action: "J6: record PHYSICAL_OUTCOME after the first print and the OD-T01 bench pressure test (REQ-12); spec 1.4 (vertical mouth-down sentence) awaits the Usta's ratification"
data_class: PUBLIC
size: M
process: [FDM]
gate_sections: [U, D, J, E]
spec: "00_Spec/DESIGN_SPEC.md"
spec_version: "1.3"
workspace: "${OGUZ_JOBS}/20260930-od-g01-group-head-housing"
delivery: "${OGUZ_DELIVERY}/20260930-od-g01-group-head-housing"
artifacts: "${OGUZ_ARTIFACTS}/20260930-od-g01-group-head-housing"
repo_commit: e0b3c9471554d989fb8dc8cdc006c93c02a40ac5
active_target: od_g01_housing_v03
revision: A
open_assumptions: [A-01, A-02, A-03, A-04, A-05, A-06, A-07, A-08, A-09, A-10, A-11, A-12, A-13, A-14, A-15, A-16, A-17, A-18, A-19, A-20, A-21, A-22, A-23, A-24, A-25, A-26, A-27, A-28]
attempts: {build: 2, export: 0, tool: 0}
caps: {build: 2, export: 2, tool: 2, fix_cycles: 3}
reviews:
  - {id: RV01, target: od_g01_housing_v03, verdict: REVISE, blockers: 1, date: "2026-09-30"}
usta_gates:
  - {gate: spec_ratified, outcome: "1.0", date: "2026-09-30"}
  - {gate: concept_picked, outcome: C1, date: "2026-09-30"}
  - {gate: spec_ratified, outcome: "1.1", date: "2026-09-30"}
  - {gate: halt_decision, outcome: another_round, date: "2026-09-30"}
  - {gate: spec_ratified, outcome: "1.2", date: "2026-09-30"}
  - {gate: spec_ratified, outcome: "1.3", date: "2026-09-30"}
  - {gate: revise_decision, outcome: accept_deviations, date: "2026-10-02"}
deliverables: [STEP, STL, scripts, REPORT]
physical_outcome: n/a
client_source_delete_after: null
---

<!--
JOB.md is the job's state and its resume point (PLAYBOOK §5). Only
tools/jobstate.py writes it (D-032), at the end of every orchestrator turn. Keep the
whole file under 5,000 tokens so it survives compaction whole: no narrative, no
logs, no measurements (those live in REPORT, VERDICT, and EVENTS.jsonl).

The SessionStart hook prints job_id, code, lane, data_class, state, blocked_on,
active_target, attempts against caps, next_action, open_assumptions, and the notes
section below.

Counters: build counts the designer packages sent for the active target (in the RE
lane, the re-drafter packages for the active feature), a RETURNED submission
included; export and tool count retries in the current step. Counters reset only
when a new target or RE feature starts, or when the Usta orders another round.
Reaching a cap is a halt (PLAYBOOK rule 9). fix_cycles goes into the designer's brief
and bounds its own fix-and-re-measure loop.
-->

## Notes for a resuming session

Cloud container job (2026-09-30): the record is mirrored to open-dedica/chassis/reports/OD-G01_group_head_housing/ after every stage; recreate the workspace from there (its README). Env: source the OGUZ env file before every tools call. Intake attempt 1 died with a session interrupt (see the note event). Usta gates of 2026-09-30 rest on the standing instruction and want explicit confirmation.

## Close summary

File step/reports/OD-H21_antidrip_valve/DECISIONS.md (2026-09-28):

# DECISIONS — OD-H21_antidrip-valve

Human decisions that gate this run. One entry per decision; never edit an old entry,
append a new one. Format: `- <date> | <who> | <decision id> | <decision> | <evidence path>`

Decision ids: REGIME (band regime chosen at intake), MEASUREMENTS (calipers supplied /
proceed scan-only), PART-CLASS (unsupported class: proceed or stop), ACCEPT-BAND
(BAND_NOT_MET accepted for delivery), HALT (reason and options), INDEP (verify could not
run in a fresh context), OTHER.

- 2026-09-28 | Ikbal (owner, session message) | MEASUREMENTS | No calipers; proceed scan-only (user message: "p95 plastik parça toleransı kullan. STL ve image ler ekte."; no measurements supplied). Limitations carried to verdict: "Tier-1 not run" and "absolute scale not caliper-verified", re-run trigger: any caliper reading. Photos are catalogue images without a scale reference: feature identification / plausibility only. | session message; input/INPUT_HASHES.json
- 2026-09-28 | Ikbal (owner, session message) | REGIME | baseline-skill, material_class plastic: p95 <= 0.30 / max <= 0.80 mm (baseline/skills/stl2step-build123d/SKILL.md:87). User wrote "p95 plastik parça toleransı kullan" = the baseline-skill plastic class, same regime as OD-H22. Declared before any gate numbers exist. | session message; intake/regime.json
- 2026-09-28 | orchestrator (agent) | OTHER | scan_resolution recorded as `full` by agent inference, not stated by the owner: 600,142 faces, mean edge 0.152 mm, 30.0 MB, same scanner/export family as OD-H22 (495,881 faces, mean edge 0.154 mm) which the owner confirmed full-res on 2026-09-25. Owner to confirm; if it is a decimated export, the verdict is capped at APPROVED_WITH_LIMITATIONS. | input/INPUT_HASHES.json#scan_resolution
- 2026-09-28 | orchestrator (agent) | OTHER | Verify it1 verdict REVISE (gate dd052135f7c2, errors empty): geometric causes named for nozzle latch window, ring windows, skirt slits. Routed --route geometry (loop 2 of 3): measure/ and build/MODELING_PLAN.md + model.py carried forward; change only those three features. The unscanned nozzle-bore-floor CAD->scan term is a coverage fact, not a rebuild target. | _it1_SUPERSEDED/qa/gate.json
- 2026-09-28 | Ikbal (owner, session message "del'ver") | ACCEPT-BAND | Accept and deliver: accepts cad_to_scan_observable, zone:I1 nozzle spigot OD lugs latch:cad_to_scan and zone:I5 ring windows:cad_to_scan band misses, gate a7a0a18a5df9 (created 2026-09-28T14:32:56+00:00); remaining misses are unscanned bore floor and scanner bridge membranes, no rebuild target left per independent verify it2. | decisions/accept_band.md

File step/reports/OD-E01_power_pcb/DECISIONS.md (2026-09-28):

# DECISIONS — OD-E01_Power-PCB

Human decisions that gate this run. One entry per decision; never edit an old entry,
append a new one. Format: `- <date> | <who> | <decision id> | <decision> | <evidence path>`

Decision ids: REGIME (band regime chosen at intake), MEASUREMENTS (calipers supplied /
proceed scan-only), PART-CLASS (unsupported class: proceed or stop), ACCEPT-BAND
(BAND_NOT_MET accepted for delivery), HALT (reason and options), INDEP (verify could not
run in a fresh context), OTHER.

- 2026-09-28 | Ikbal (owner brief) | REGIME | baseline-skill, material class plastic: p95 <= 0.30 / max <= 0.80 mm ("p95 plastik parça toleransı kullan") | decisions/owner_brief.md
- 2026-09-28 | Ikbal (owner brief) -> agent | MEASUREMENTS | scan-only: no caliper sheet supplied, owner asked for a finished zip delivery; limitations "Tier-1 not run" and "absolute scale not caliper-verified" carried to the verdict | decisions/owner_brief.md
- 2026-09-28 | agent (delegated by owner brief) | PART-CLASS | populated PCB assembly (board + components) modelled as ONE fused envelope solid of analytic primitives (board plate, component boxes/cylinders, extruded heatsink profile); no multi-body assembly, no electrical detail (pads, traces, silkscreen, solder) | decisions/owner_brief.md
- 2026-09-28 | agent | OTHER | scan_resolution declared "full": the supplied STL (398,079 faces, 19.9 MB) is the only and original file, not a *_decimated copy | input/INPUT_HASHES.json
- 2026-09-28 | agent | OTHER | datum try 1 STOP (board-top rms 0.0342 > film-cap noise 0.0275) caused by board bow/twist (~-0.2..+0.1 mm) and copper-trace relief; re-ran align with the noise floor measured on the board top itself (self-referential, OD-H22 precedent); try 1 kept in intake/_datum_try1_STOP/ | intake/INTAKE_CARD.md
- 2026-09-28 | agent (orchestrator) | OTHER | it1 verdict REVISE (independent verify, qa gate in _it1_SUPERSEDED/qa/gate.json): fixable misses routed to measure (C5 underside, J3 cavity floor, TO-220 tab hole position, K2 bump, clip lower hook); supersede --route measure; the run-local scripts measure_pcb.py, make_params.py, model.py and MODELING_PLAN.md copied forward as the diffable base | _it1_SUPERSEDED/qa/review.json
- 2026-09-28 | Ikbal (owner) | ACCEPT-BAND | accept scan_to_cad:masked and cad_to_scan_observable misses of the it2 BAND_NOT_MET gate 948b8a16472b for delivery | decisions/accept_band_it2.md

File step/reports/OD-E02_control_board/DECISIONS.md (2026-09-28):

# DECISIONS — OD-E02_control-button-board

Human decisions that gate this run. One entry per decision; never edit an old entry,
append a new one. Format: `- <date> | <who> | <decision id> | <decision> | <evidence path>`

Decision ids: REGIME (band regime chosen at intake), MEASUREMENTS (calipers supplied /
proceed scan-only), PART-CLASS (unsupported class: proceed or stop), ACCEPT-BAND
(BAND_NOT_MET accepted for delivery), HALT (reason and options), INDEP (verify could not
run in a fresh context), OTHER.

- 2026-09-28 | Ikbal (owner, session message) | REGIME | baseline-skill, material_class plastic: p95 <= 0.30 / max <= 0.80 mm (baseline/skills/stl2step-build123d/SKILL.md:87). User wrote "p95 plastik parça toleransı kullan". Declared before any gate numbers exist. | session message; intake/regime.json
- 2026-09-28 | Ikbal (owner, session message) | MEASUREMENTS | No calipers supplied ("STL ve image ler ekte"); proceed scan-only. Limitations carried to verdict: "Tier-1 not run" and "absolute scale not caliper-verified", re-run trigger: any caliper reading. Photos (2 catalogue images, no scale reference) are feature identification / plausibility only. | session message; input/INPUT_HASHES.json
- 2026-09-28 | Ikbal (owner, question card) | OTHER | scan_resolution confirmed full-res (original scanner export, 586,137 faces, mean edge 0.247 mm). | input/INPUT_HASHES.json#scan_resolution
- 2026-09-28 | Ikbal (owner, session message) | OTHER | Delivery format: one downloadable zip with all source files and deliverables (standing format, stl-re-deliver/references/delivery-package.md). | session message
- 2026-09-28 | builder (agent) | OTHER | Intake CHK-ENUM missed four sub-features (inner latch bosses, hoop catch ramps, cap-collar recesses, side-collar tilted cut); the builder self-check (not QA) found them inside iteration 1 before verify; measure re-ran and params were regenerated each time (build/MODELING_PLAN.md §8). Not a loop: no verify verdict existed. | build/MODELING_PLAN.md; intake/INTAKE_CARD.md E15-E18
- 2026-09-28 | orchestrator (agent) | OTHER | Verify it1 verdict REVISE (gate errors empty, allowed BAND_NOT_MET/HALT/REVISE). Chose REVISE (loop 1 of 3, route geometry): verify names fixable geometry (band/T3 seam, band ends, header base inside the shroud, B1 collar floor). Remaining expected miss after it2: CAD->scan observable in unscanned openings. | qa/VERDICT.md
- 2026-09-28 | orchestrator (agent) | OTHER | Verify it2 verdict REVISE (gate errors empty). Loop 2 of 3 used; chose REVISE again, route geometry: verify names the B1 cap lip inside the cap-collar gap and over-deep recess ceilings as fixable. This is the last allowed loop; a REVISE at it3 means HALT. | qa/VERDICT.md
- 2026-09-28 | Ikbal (owner, question card) | ACCEPT-BAND | Accept and deliver: accepts scan_to_cad:masked (max) and cad_to_scan_observable (p95, max) band misses, gate 1e9b7dcea587 (created 2026-09-28T08:54:19+00:00); 98.5% of the CAD->scan miss is in unscanned openings (shroud interior, shroud-to-rim slot, screw bores). | decisions/accept_band.md

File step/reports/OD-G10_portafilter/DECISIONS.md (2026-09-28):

# DECISIONS — OD-G11_portafilter

Human decisions that gate this run. One entry per decision; never edit an old entry,
append a new one. Format: `- <date> | <who> | <decision id> | <decision> | <evidence path>`

Decision ids: REGIME (band regime chosen at intake), MEASUREMENTS (calipers supplied /
proceed scan-only), PART-CLASS (unsupported class: proceed or stop), ACCEPT-BAND
(BAND_NOT_MET accepted for delivery), HALT (reason and options), INDEP (verify could not
run in a fresh context), OTHER.

- 2026-09-28 | Ikbal (owner, session message) | MEASUREMENTS | No calipers; proceed scan-only (message: "p95 plastik parça toleransı kullan. STL ve image ler ekte."). Limitations carried to verdict: "Tier-1 not run" and "absolute scale not caliper-verified", re-run trigger: any caliper reading. Photos (2, no scale reference) are feature-identification/plausibility only. | input/INPUT_HASHES.json
- 2026-09-28 | Ikbal (owner, session message) | REGIME | baseline-skill, material_class plastic: p95 <= 0.30 / max <= 0.80 mm (baseline/skills/stl2step-build123d/SKILL.md:87). Owner wrote "p95 plastik parça toleransı kullan" before any gate numbers exist. | intake/regime.json
- 2026-09-28 | Ikbal (owner, decision card) | OTHER | scan_resolution confirmed full-res ("Evet, orijinal export"; 500,182 faces). Run re-initialised with --scan-resolution full before any stage beyond intake stats (same scan sha256 9eb34045f9be…). | input/INPUT_HASHES.json
- 2026-09-28 | Ikbal (owner, decision card) | PART-CLASS | The scan is an assembly (cast body, handle, pressurised basket insert, wire spring clip, spout screws) captured as one mesh. Owner chose "Tek birleşik katı": deliver ONE fused solid of the whole portafilter as scanned; wire clip and screw heads may be simplified and are declared. | input/photos/1.webp, input/photos/2.webp
- 2026-09-28 | orchestrator (agent) | OTHER | it1 verdict REVISE (qa/gate.json errors [], allowed BAND_NOT_MET/HALT/REVISE). Loop 1 of 3 used. Route `measure`: every named cause is a measurement miss on scanned surfaces (floor trough near the wall/pockets, V-rib inner ends, U-rib round end, lug ramp ends, arch foot curvature, wire arcs), not a datum problem (datum audit 0.003 deg / 0.063 mm). it2 re-measures only those features; everything else is regenerated by the same measurement scripts unchanged. | qa/VERDICT.md
- 2026-09-28 | orchestrator (agent) | OTHER | it2 verify (fresh agent, same protocol as it1): BAND_NOT_MET, gate errors [], allowed BAND_NOT_MET/REVISE/HALT. Loop 2 of 3. Verifier: the remaining misses are unscanned regions and declared simplifications that a third loop cannot clear without new scan data. | qa/VERDICT.md
- 2026-09-28 | Ikbal (owner, session message) | ACCEPT-BAND | "tamam, band kaçarsa kabul ediyorum, teslim et": accepts scan_to_cad:masked (max) and cad_to_scan_observable (p95, max) misses for delivery, gate 0f2d41f2bdd2 (created 2026-09-28T11:17:26+00:00). | decisions/accept_band.md

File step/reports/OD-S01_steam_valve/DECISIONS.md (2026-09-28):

# DECISIONS — OD-S01_steam-valve

Human decisions that gate this run. One entry per decision; never edit an old entry,
append a new one. Format: `- <date> | <who> | <decision id> | <decision> | <evidence path>`

Decision ids: REGIME (band regime chosen at intake), MEASUREMENTS (calipers supplied /
proceed scan-only), PART-CLASS (unsupported class: proceed or stop), ACCEPT-BAND
(BAND_NOT_MET accepted for delivery), HALT (reason and options), INDEP (verify could not
run in a fresh context), OTHER.

- 2026-09-28 | Ikbal (owner, session message) | REGIME | baseline-skill, material_class plastic: p95 <= 0.30 / max <= 0.80 mm (baseline/skills/stl2step-build123d/SKILL.md:87). User wrote "p95 plastik parça toleransı kullan". Declared before any gate numbers exist. | session message; intake/regime.json
- 2026-09-28 | Ikbal (owner, question card) | MEASUREMENTS | No calipers; proceed scan-only ("Yes, scan-only"). Limitations carried to verdict: "Tier-1 not run" and "absolute scale not caliper-verified", re-run trigger: any caliper reading. Photos 1-5 are catalogue images without scale reference: feature identification / plausibility only. | session question card; input/INPUT_HASHES.json
- 2026-09-28 | Ikbal (owner, question card) | OTHER | scan_resolution confirmed full-res ("Yes, original full-res"); 499,756 faces, mean edge 0.206 mm, one body. | input/INPUT_HASHES.json#scan_resolution
- 2026-09-28 | Ikbal (owner, session message) | OTHER | Delivery format: one zip with all deliverables + all source files (standing format, skills/stl-re-deliver/references/delivery-package.md). | session message
- 2026-09-28 | orchestrator (agent) | OTHER | REVISE (it1, qa/VERDICT.md) routed --route datum, not verify's suggested 'measure': two findings are CHK-ENUM gaps (bump under the switch, column lug at 320 deg), which orchestrate §4 routes to intake feature enumeration; the datum itself is kept (same spec, deterministic re-run). Loop 2 of 3. | qa/VERDICT.md
- 2026-09-28 | Ikbal (owner, question card) | ACCEPT-BAND | Accept and deliver: accepts scan_to_cad:masked, cad_to_scan_observable and zones Z1/Z2/Z3/Z4/Z6 band fails, gate 19f6d742b0ae (created 2026-09-28T08:12:03+00:00); scan->CAD p95 0.449 max 1.94, observable CAD->scan p95 0.761 max 2.89; loop 3 judged unable to reach the band (QA probe) | decisions/accept_band.md

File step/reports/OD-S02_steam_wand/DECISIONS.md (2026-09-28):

# DECISIONS — OD-S02_steam-rod

Human decisions that gate this run. One entry per decision; never edit an old entry,
append a new one. Format: `- <date> | <who> | <decision id> | <decision> | <evidence path>`

Decision ids: REGIME (band regime chosen at intake), MEASUREMENTS (calipers supplied /
proceed scan-only), PART-CLASS (unsupported class: proceed or stop), ACCEPT-BAND
(BAND_NOT_MET accepted for delivery), HALT (reason and options), INDEP (verify could not
run in a fresh context), OTHER.

- 2026-09-28 | Ikbal (owner, task message) | REGIME | baseline-skill, material_class plastic: p95 <= 0.30 / max <= 0.80 mm (baseline/skills/stl2step-build123d/SKILL.md:87). User wrote "p95 plastik parça toleransı kullan". Declared before any gate numbers exist. | task message; intake/regime.json
- 2026-09-28 | Ikbal (owner, task message) | MEASUREMENTS | No calipers supplied; proceed scan-only (message gives STL + 2 photos only). Limitations carried to verdict: "Tier-1 not run" and "absolute scale not caliper-verified", re-run trigger: any caliper reading. Photos have no scale reference: feature identification / plausibility only. | task message; input/INPUT_HASHES.json
- 2026-09-28 | Ikbal (owner, question card) | OTHER | scan_resolution confirmed full-res: "Evet, orijinal" (original scanner export, 499,164 faces). | input/INPUT_HASHES.json#scan_resolution
- 2026-09-28 | Ikbal (owner, question card) | PART-CLASS | The scan is one mesh of an assembly (black knob+lever, black connector rod with O-rings, black sleeve, steel tube, white bushing, steel tip). Owner chose "Tek birleşik katı": deliver ONE fused solid; inter-part boundaries are modelled as features, hidden geometry inside the assembly is not modelled (declared). Multi-body STEP is a separate job. | question card
- 2026-09-28 | orchestrator (agent) | OTHER | Datum STOP-rule estimator mismatch, same class as OD-H22 D1. Primary = rod taper axis (cone residual about linear r(t), section-circle refined) rms 0.0255; origin circle stations (Kåsa) median 0.0214; the only circle noise floor available on this surface is datum_fit.py noise = IRLS on ONE loop of the same taper, 0.0144 (intake/noise_circle.json), while plain Kåsa station rms on the taper is 0.021. The taper is the cleanest surface of the part (no cleaner region exists). Proceeded on the documented self-referential path: noise_secondary omitted, align.py records "not compared" findings; the steel clock axis is still gated against a steel noise floor measured on a disjoint stretch (intake/noise_steel.json 0.0514 vs clock 0.0495). Verify re-derives the datum independently. | intake/alignment.json; intake/noise_circle.json; intake/noise_steel.json
- 2026-09-28 | orchestrator (agent) | OTHER | Process deviations declared: (a) intake/INTAKE_CARD.md and intake/MEASUREMENTS.md were rendered (intake/write_card.py, from the frozen intake JSONs) after the measure pass, no intake number changed; (b) build/MODELING_PLAN.md was written after the self-check build passes (plan §0/§8). Both are recorded, not hidden. | build/MODELING_PLAN.md; intake/write_card.py
- 2026-09-28 | orchestrator (agent) | OTHER | it1 verdict REVISE (route geometry, independent verify, errors []): bushing windows (qa clusters 2+3). `init_run.py supersede --route geometry` -> _it1_SUPERSEDED/. it2 changed exactly two params from assumed to scan lower bounds (bush_window_depth, tip_bore_depth; measure/figures/revise_it2_probe.json). Loop 2 of 3. Re-verify in a fresh agent with the it1 gate protocol (CHK-LIKE4LIKE). | _it1_SUPERSEDED/qa/VERDICT.md; build/MODELING_PLAN.md §8
- 2026-09-28 | orchestrator (agent) | OTHER | it2 verdict REVISE (route geometry, independent verify, errors []): Z2 bend, Z3 lever perimeter, Z4 hub. `supersede --route geometry` -> _it2_SUPERSEDED/. it3 (LAST loop, 3 of 3) changes only those three features, each re-measured on the scan (measure/figures/measure_it3.json): bend spline + bend_tube_r, paddle_edge_fillet_r 1.2 -> 1.946, tip_neck. Non-geometric misses (D1 flash unmasked, CAD over scan holes, unscanned pocket floors/bore) are expected to remain; any REVISE after it3 is a HALT by rule. | build/MODELING_PLAN.md §8; _it2_SUPERSEDED/qa/VERDICT.md
- 2026-09-28 | orchestrator (agent) | HALT | it3 (loop 3 of 3) independent verdict REVISE (route geometry; errors [], allowed BAND_NOT_MET/HALT/REVISE): REVISE at loop 3 -> HALT (RE_SPEC.md:250; orchestrate §4/§6). Remaining band_fails: observable CAD->scan (unscanned window floors/bore, scan holes), Z4 CAD->scan (same cause), Z4 scan->CAD p95 0.301 vs 0.30 (unmodelled raised collar on the bushing top at the tube-C entry, 75 % of its points within 0.8 mm of a scan-hole edge). Options put to the owner: accept (ACCEPT-BAND) / one extra owner-authorised loop for the collar / more data / stop. No deliver/ created. | qa/VERDICT.md; qa/gate.json
- 2026-09-28 | Ikbal (owner, question card) | OTHER | HALT resolved by the owner: "Kabul et, teslim et". The owner accepts the it3 band misses (incl. the marginal geometric Z4 scan->CAD p95 0.301 vs 0.30 from the unmodelled bushing-top collar) instead of a 4th loop; verify is asked to re-assemble the it3 verdict as BAND_NOT_MET (a member of gate 69b36b1ef4d5's allowed_verdicts) with the same numbers; the ACCEPT-BAND line follows, citing the re-assembled gate. | question card; qa/gate.json (69b36b1ef4d5, created 2026-09-28T09:27:39+00:00)
- 2026-09-28 | Ikbal (owner, question card) | ACCEPT-BAND | Accept and deliver: accepts cad_to_scan_observable, zone:Z4 bushing + tip:scan_to_cad and zone:Z4 bushing + tip:cad_to_scan band misses, gate 34a11505e84d (created 2026-09-28T09:57:42+00:00); unscanned window floors/bore and scan holes cannot be fixed by geometry, the marginal Z4 scan->CAD cause (bushing-top collar) is declared as L6. | decisions/accept_band.md

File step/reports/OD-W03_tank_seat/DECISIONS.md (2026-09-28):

# DECISIONS — OD-W03

Human decisions that gate this run. One entry per decision; never edit an old entry,
append a new one. Format: `- <date> | <who> | <decision id> | <decision> | <evidence path>`

Decision ids: REGIME (band regime chosen at intake), MEASUREMENTS (calipers supplied /
proceed scan-only), PART-CLASS (unsupported class: proceed or stop), ACCEPT-BAND
(BAND_NOT_MET accepted for delivery), HALT (reason and options), INDEP (verify could not
run in a fresh context), OTHER.

- 2026-09-28 | Ikbal (owner, session message) | REGIME | baseline-skill, material_class plastic: p95 <= 0.30 / max <= 0.80 mm (baseline/skills/stl2step-build123d/SKILL.md:87). Owner wrote "p95 plastik parça toleransı kullan"; translucent moulded plastic part. Declared before any gate numbers exist. | session message; intake/regime.json
- 2026-09-28 | Ikbal (owner, decision card) | MEASUREMENTS | No calipers; proceed scan-only ("Sadece tarama ile ilerle"). Limitations carried to verdict: "Tier-1 not run" and "absolute scale not caliper-verified", re-run trigger: any caliper reading. The single catalogue photo has no scale reference: feature identification / plausibility only. | session decision card
- 2026-09-28 | Ikbal (owner, decision card) | OTHER | scan_resolution confirmed full ("Evet, orijinal tam çözünürlük"): 400,657 faces, mean edge 0.184 mm, one body. | input/INPUT_HASHES.json
- 2026-09-28 | Ikbal (owner, decision card) | OTHER | Interior design intent: hollow moulded shell ("İçi boş kabuk"). Cups and middle boss open from below, assumed wall thickness 1.2 mm, barb bore opens into its cup. Every interior dimension is `assumed` and declared (the underside and all interiors are unscanned). | session decision card; intake/coverage.json
- 2026-09-28 | orchestrator (agent) | OTHER | Datum: secondary (cup A/B outer wall, z 1.2-3.6) median circle rms 0.0815 vs the independent barb-shank circle noise 0.0708 (z=16) -> align.py STOP by 0.011 mm. Barb shanks as origin were worse (0.089); higher cup bands carry +/-0.15 mm scan ripple. Took the self-referential noise path (intake/noise_cups.json, OD-H22 D1 precedent: no tie margin); centre scatter per cup <= 0.007 mm over 3 stations of ~3,300 faces. Primary plane noise is also measured on the primary itself (flange top). Added align.py `feature_line` clock and `combine: midpoint` origin (fourier_mass n=2 was 0.7 deg off the cup line; pooled median picked one cup's centre). | intake/alignment.json; intake/noise_cups.json; intake/datum_spec.json
- 2026-09-28 | Ikbal (owner, decision card) | ACCEPT-BAND | Accept and deliver now: accepts scan_to_cad and cad_to_scan_observable band misses, gate 2fe9569f1fa0 (created 2026-09-28T08:17:23+00:00); REVISE for the cup B upper wall offered and declined. | decisions/accept_band.md

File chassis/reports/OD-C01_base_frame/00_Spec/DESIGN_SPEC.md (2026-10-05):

# DESIGN_SPEC — OD-C01 printed base frame (20260930-od-c01-base-frame)

Version 1.3 · RATIFIED by the Usta on 2026-10-05 ("continue now", answering the base-plate card on its recommended option) · data class PUBLIC · size M · lane CAD

## §1 Intent

OD-C01 is the 3D-printed base frame of the Open Dedica espresso machine: the floor
plate every printed mount stands on and screws into. It fixes the machine layout
(§4, A-01 … A-06): the group head carrier OD-C05 at the front, the thermoblock mount
OD-C04 behind it, the pump cradle OD-C03 across the back, the drip tray in front
under the group head, the water tank at the rear, the valve and flowmeter mount on
the left, the electronics bay on the right behind the bulkhead OD-C02. Done means:
one valid printable plate with a flat top face (the floor plane every mount's spec
names), M3 heat-set insert holes under the three existing mounts' foot holes and
along the bulkhead line, screw holes for four feet, two drain holes in the wet zone,
reserved zones for the parts not yet designed, and every unconfirmed value in §6.
The drip tray OD-C21/C22 and the tank OD-W01 are not scanned, the tank dock OD-C06
is deferred (the tank stands on the table, the Usta 2026-10-02): their zones are
assumptions. OD-C07, OD-C08, OD-C10, OD-C11 and OD-C15 are delivered; 1.3 adds the
eighteen inserts OD-C08, OD-C11, the side-panel brackets OD-C16 and the front
panel OD-C09 screw into (REQ-11 … REQ-14).

**Deliverables** (tier M): STEP AP242 of the plate; the check assembly STEP (plate +
OD-C03 with OD-H01 + OD-C04 with OD-H11 + OD-G01 v02 at the carrier's pose, each by
its joint of §4); STL and 3MF; build and check scripts; REPORT; sections. No
drawings or renders.

**Out of scope:** the other parts themselves, the tray, tank, dock, side and front
panels, the tube runs, calipers. Revision B (1.3) changes only the insert holes and
the material; every other feature of build v02 stands.

## §2 Interfaces and confirmed dimensions

| Item | Value | Tolerance | Source | Status |
|---|---|---|---|---|
| OD-C03 pump cradle (delivered) | `00_Spec/inputs/OD-C03_pump_cradle.step` (INTAKE §1 #1): foot underside its y = +40.0 (+Y down), holes Ø3.4 at (x ±34.0, z −4.0 / 37.0) in its frame | — | OD-C03 spec 1.2 §4, REQ-07, REQ-08, A-11 (INTAKE X-01 … X-06) | CONFIRMED as the input; A-03 places it |
| OD-C04 thermoblock mount (delivered) | `00_Spec/inputs/OD-C04_thermoblock_mount.step` (#2): foot underside its y = −70.0 (−Y down), holes Ø3.4 at (x ±40.0, z −8.0 / 26.0) | — | OD-C04 spec 1.2 §4, REQ-05, REQ-06, A-10 (X-12 … X-17) | CONFIRMED as the input; A-02 places it |
| OD-C05 group head carrier (in design) | spec 1.0 → 1.1 (A-01): foot underside its y = −175.0 (+Y up), holes Ø3.4 at (x ±35.0, z −40.0 / −60.0), wall z −29.94 … −24.94 | — | OD-C05 spec §4, REQ-05, REQ-06, A-03, A-04 (X-23 … X-33) | CONFIRMED as the input; A-01 places it |
| OD-H01 pump, OD-H11 thermoblock, OD-G01 housing v02 | `00_Spec/inputs/OD-H01_ulka_ep5_pump.step`, `OD-H11_thermoblock.step`, `OD-G01_housing_C1_v02.step` (#3 … #5), placed by the joints their mounts' specs state, in the mounts' frames | — | OD-C03 spec §2 (identity), OD-C04 spec §2 (identity), OD-C05 spec §2 (identity) | CONFIRMED as the inputs |
| OD-C08 electronics bay tray (delivered) | `00_Spec/inputs/OD-C08_electronics_bay_tray.step`: modelled in the machine frame, placed at the identity; flange underside on y 0; four Ø3.4 flange holes along Y at (x 88, z −222), (106, −222), (88, −78), (106, −78) | — | OD-C08 spec 1.0 §4, U-05, D-04a; integration notes 2026-10-01 | CONFIRMED as the input; A-18 places it |
| OD-C11 back panel (delivered, build v03) | `00_Spec/inputs/OD-C11_back_panel.step`: machine frame, identity; floor flanges on y 0; four Ø3.4 holes along Y at (x ±81, z −282) and (x ±95, z −282); its wall inner face at z −299 | — | OD-C11 spec 1.2 §4, U-05; integration notes 2026-10-01 | CONFIRMED as the input; A-18 places it |
| Fasteners | M3 heat-set inserts (OD-F01) in this plate, M3 × 8 screws (OD-F02) | — | open-dedica `docs/bom.csv` (INTAKE §3) | CONFIRMED (project standard) |

**Coordinate frame (the machine frame):** X to the user's right, **+Y up**, +Z toward
the user (the front); the origin lies on the group head axis' vertical, on the
floor plane: y = 0 is the plate's top face, the floor plane every mount's foot
stands on (INTAKE X-01, X-12, X-23; §4 gap 11 answered by A-01 … A-03); the group
head axis is the line (x 0, y 175) along Z, and its housing's rear face is the plane
z = −24.94, as in OD-C05's frame. The plate occupies y −6.0 … 0. Every artifact of
this job uses this frame; the three mounts' local frames map into it by the joints
of §4 (A-01 … A-03), which answer INTAKE §4 gap 1.

## §3 Process, material, environment

| Part | Process | Machine profile | Material (grade) | Density kg/m³ | Finish | Status |
|---|---|---|---|---|---|---|
| od_c01_frame | FDM | machines/anycubic-kobra-max-3.toml (build volume UNKNOWN → A-09) | PLA for now (the Usta, 2026-10-02: all prints in PLA); service material PETG or ASA stays A-10 | 1240 | as printed | A-10 |

Environment: the bottom of the machine, on the counter through four feet; the wet
zone (left and centre) sees drips and leaks that must reach the tray, not the
electronics (INTAKE X-41, X-49); the thermoblock stays ≥ 10 mm above the plate by
its mount's design (OD-C04: lowest casting point 16.5 above the floor, INTAKE X-17);
loads: the mounts and their OEM parts (≈ 0.5 kg pump, ≈ 0.45 kg thermoblock, the
group head with the portafilter and the user's locking torque), the tank (≈ 1 kg
full), a hand pressing the buttons.

## §4 Architecture and concepts

- **C1 — one flat plate with insert holes, feet holes, drain holes and reserved
  zones (CHOSEN).** One solid. A plate 6.0 thick, y −6.0 … 0, spanning x −120 …
  +120 and z −305 … +100 (corners R 10), printed flat, top face up. The layout in
  this frame (every joint is a translation and a rotation of a mount's own frame):
  - **OD-C05 carrier and the group head** (A-01, 1.2): the group head axis is
    vertical, the mouth down (OD-C05 spec 2.0 A-02, RV01 F1). The carrier's frame
    (the OD-G01 housing frame) maps by the proper rotation local x → X, local
    y → +Z, local z → −Y, its origin at (0, 180.06, 32.0), so its foot underside
    (its z +180.06) lands on y 0, the housing's rear face (its z −24.94) lies at
    y 205.0 and the housing's mouth face (its z +3.30) at y 176.76; the carrier's
    holes at (x ±35, z −40) and (x ±35, z −60) (unchanged); its foot occupies
    x ±55, z −70 … −26, its wall z −26 … −20 up to y 210, its plate z −26 … +82 at
    y 205 … 210; the housing occupies x ±50, z −18 … +82; the portafilter spouts
    hang to y ≈ 135.2 (OD-C05 spec 2.0 A-03).
  - **OD-C04 thermoblock mount** (A-02): its frame at the identity rotation (its
    −Y is down, its +Z toward the group head), its origin at (0, 70, −140), so its
    foot underside y −70 lands on y 0; its holes at (x ±40, z −148) and
    (x ±40, z −114); its foot occupies x ±50, z −157 … −107; the thermoblock's
    outlet pins reach z −89.21 (its z 50.79), so the casting stays behind z −85 as
    OD-C05 A-05 assumes, 19.3 behind the carrier's foot, and its lowest point sits
    16.5 above the plate.
  - **OD-C03 pump cradle** (A-03): the pump axis along X across the back; its
    frame rotated so that its local x → +Z, local y → −Y, local z → +X (a proper
    rotation), its origin at (0, 40, −205), so its foot underside (its y +40)
    lands on y 0, the pump axis lies at y 40, its holes at (x −4, z −239),
    (x −4, z −171), (x 37, z −239), (x 37, z −171); its foot occupies x −10 … 42,
    z −245 … −165; the pump spans x −66.45 … +55.5 with its outlet toward −X (the
    valve side, A-05).
  - **Bulkhead line OD-C02** (A-04): the plane x = 65 from z −240 to −30, with four
    insert holes at (x 65, z −45), (65, −105), (65, −165), (65, −225) for the
    bulkhead's foot; everything at x ≥ 70 behind it is the electric zone.
  - **Reserved zones** (A-05 … A-08, documented in the plan, not gated): the drip
    tray x ±75, z −15 … +85 on the plate under the mouth at (0, 32) (cup rest top
    ≤ 36.9 above the plate, A-06; 1.2 moved it back 25 with the housing); the water tank x ±70, z −305 … −250 (A-07); the valve and flowmeter
    mount OD-C07 x −117 … −67, z −154 … −35 (A-05); the electronics bay x 70 … 120,
    z −240 … −30 (A-08).
  - **OD-C07 valve and flowmeter mount** (A-17, added in 1.1): its frame rotated so
    that its local x → −Z, local y → −X, local z → +Y (a proper rotation), its
    origin at (−92, 0, −60), so its bottom face lands on y 0, its flowmeter end
    faces the front and its valve end the pump; its footprint holes (its
    (−18, ±21) and (88.5, ±21)) land at (x −113, z −42), (x −71, z −42),
    (x −113, z −148.5), (x −71, z −148.5); its envelope (119 × 50 × 48 in its frame)
    occupies x −117 … −67, z −154 … −35, up to y 48; its hose window (its
    x 40 … 84, y ±25) lies over z −144 … −100, so the drain hole at (−80, −120)
    sits under it. The pump's −X end (x −66.45, z ≤ −165) stays ≥ 11 behind the
    mount's rear end (z −154).
  - **OD-C08 tray and OD-C11 back panel** (A-18, added in 1.3): both modelled in
    this frame and placed at the identity. Four insert holes under the tray's flange
    at (x 88, z −222), (106, −222), (88, −78), (106, −78), inside the electronics bay
    (A-08); four under the back panel's floor flanges at (x ±81, z −282) and
    (x ±95, z −282), outside the tank zone's x ±70.
  - **OD-C16 side-panel brackets** (A-19, added in 1.3): three per side, each one
    M3 down into an insert at (x ±104.5, z −262), (±104.5, −15), (±104.5, +62).
  - **OD-C09 front panel** (A-20, added in 1.3): modelled in this frame, placed at
    the identity; its two floor flanges screw into inserts at (x ±85, z +77) and
    (x ±95, z +77).
  - **Insert holes**: thirty-eight Ø4.0 through-holes along Y (sixteen under the four
    mounts, four on the bulkhead line, four under OD-C08, four under OD-C11, six
    under the OD-C16 brackets, four under OD-C09) for M3 × 5.7 heat-set inserts driven from the
    top (the 6.0 plate holds the 5.7 insert, A-11). **Feet holes**: four Ø3.4
    through-holes at (x ±110, z +90) and (x ±110, z −295) for the feet OD-C15
    (an M3 × 12 from the top into a nut captive in the foot) or the OEM pads (A-12). **Drain holes**: two Ø8.0 through-holes in the wet zone
    at (x −80, z −120) and (x −80, z −230) so a leak leaves the machine instead of
    pooling (A-13); the tray zone itself is the plate's top face.
  - Print orientation: flat, bottom face on the bed, no supports (A-14). Envelope
    240.0 × 6.0 × 405.0 (x ±120, y −6 … 0, z −305 … +100).
- **C2 — ribbed tray with a raised rim and a recessed tray well.** Stiffer and
  lighter, with the drip tray sunk into the plate. Deferred: needs the tray scan
  (INTAKE §4 gap 4) and the feet decision.
- **C3 — two half plates joined at the bulkhead line.** For a printer smaller than
  the Kobra Max 3. Deferred until A-09 is answered.

## §5 Gate table

| ID | Requirement | Threshold | Hard/Soft | CAD/part | Basis | Check | Assumes |
|---|---|---|---|---|---|---|---|
| U-01 | Valid solid per part | `solid_count = 1`, `brep_valid = 1`, `naked_edges = 0` | Hard | CAD | house | `validity` | — |
| U-02 | Envelope within spec | 240.0 × 6.0 × 405.0 each in [spec − 0.1, spec + 0.1]; position against the datum reported apart (x ±120.0, y −6.0 … 0.0, z −305.0 … +100.0) | Hard | CAD | house | `envelope` | — |
| U-03 | Assembly closes | (a) plate|OD-C03 and plate|OD-C04 at the joints of §4: designed contacts, `clearance = 0`, `interference ≤ 0` mm³; each mount's four Ø3.4 holes coaxial with the plate's Ø4.0 holes, offset ≤ 0.10 (`locate_bore` on both solids); plate|OD-H01 ≥ 2.0 and plate|OD-H11 ≥ 10.0 (`clearance`; the OD-H11 boolean is INCONCLUSIVE by OD-C04 A-14 and reported); OD-C03|OD-C04 ≥ 2.0; OD-H11 max z ≤ −85.0 (`envelope` of the placed solid); OD-G01 v02 at the carrier's pose (the joint of §4, origin (0, 180.06, 32.0), rotation x → X, y → +Z, z → −Y) ≥ 2.0 to everything else; the carrier itself is not built yet (A-01: the check assembly places its foot outline x ±55, y 0 … 4, z −70 … −26 as a reference box, not a solid); 1.3: plate|OD-C08 and plate|OD-C11 at the identity (A-18) and plate|OD-C16 × 6 at the poses of A-19 and plate|OD-C09 at the identity (A-20): designed contacts `clearance = 0`, `interference ≤ 0` mm³, each of their Ø3.4 holes coaxial with its plate Ø4.0 hole, offset ≤ 0.20 (the sum of the two parts' 0.10 position bands); every new part `interference ≤ 0` mm³ with the plate. (b) N/A | Hard | CAD | house | `clearance`, `interference`, `locate_bore`, `envelope` | A-01 … A-03 |
| U-04 | Clean export | named body re-read unchanged, no stray shells, valid after re-import | Hard | CAD | house | `step_roundtrip` | — |
| U-05 | Every spec feature present | counts per the plan: 1 plate, 38 Ø4.0 through-holes, 4 Ø3.4 through-holes, 2 Ø8.0 through-holes | Hard | CAD | house | `feature_census`, `bore_census`, `locate_bore` | — |
| U-06 | Soft: thin corners under a round | `min_wall` wide ≥ 2.0 | Soft | part | house | `min_wall` `detail["wide"]` | — |
| U-07 | Export mesh | STL at tol 0.01, angular a ≤ 4·acos(1 − 0.01/6.0) rad; `stl_max_sagitta ≤ 0.01`; the 3MF carries the same mesh | Hard | CAD | house | `write_stl`, `mesh_sagitta` | — |
| U-08 | Threads cosmetic | applies to threaded parts; this target has none | Hard | CAD | house | — (N/A by this row) | — |
| D-01a | Wall, process floor | `min_wall ≥ 0.8` at a 0.4 nozzle | Hard | part | floor | `min_wall` | — |
| D-01b | Wall, structural | `min_wall ≥ 2.0` (the default; the plate carries the machine) | Hard | part | struct | `min_wall` | — |
| D-02 | Bed fit | each envelope size ≤ the Kobra Max 3 build volume, flat: 240.0 × 405.0 on the bed, 6.0 tall | Hard | part | machine | `envelope` | A-09 |
| D-03a | Unsupported overhang | every downward face ≥ 45° from horizontal in the print orientation (flat, build direction +Y): none but the bed face; nothing supported | Hard | part | floor | `overhang_census(build_dir=(0,1,0))` | A-14 |
| D-03b | Unsupported bridge | span ≤ 5: none | Hard | part | floor | reviewer, from sections | — |
| D-04a | Clearance hole for a fastener | the four feet holes Ø ≥ 3.25 (designed Ø3.4); the drain holes are not fastener holes | Hard | part | house | `locate_bore` | A-12 |
| D-05a | Heat-set insert boss | material ≥ 8.0 across around each Ø4.0 hole (the plate itself) | Hard | part | struct | `bore_census`, `radial_extent` | A-11 |
| D-05b | Heat-set insert hole | the thirty-eight insert holes Ø 4.0 ± 0.05, depth ≥ 5.7 (through the 6.0 plate) | Hard | part | floor | `bore_census`, `locate_bore` | A-11 |
| D-06a | Minimum feature | ≥ 1.0 | Hard | part | floor | `min_wall` | — |
| D-07 | Fit-critical bores | none: insert holes are formed by the insert, the rest are clearance and drain holes | Hard | part | floor | — (N/A by this row) | — |
| J-05 | Wall around a threaded hole | ≥ 3.0 around each of the thirty-eight insert holes | Hard | part | struct | `min_wall` | — |
| E-06 | Boss support | no bosses on this part | Hard | part | struct | — (N/A by this row) | — |
| REQ-01 | Carrier inserts | four Ø4.0 ± 0.05 through-holes along Y at (x ±35.0, z −40.0) and (x ±35.0, z −60.0), offset ≤ 0.10 (OD-C05 A-04) | Hard | CAD | A-01 | `locate_bore` | A-01 |
| REQ-02 | Thermoblock mount inserts | four Ø4.0 ± 0.05 through-holes at (x ±40.0, z −148.0) and (x ±40.0, z −114.0), offset ≤ 0.10, coaxial with OD-C04's holes as placed (U-03) | Hard | CAD | A-02 | `locate_bore` | A-02 |
| REQ-03 | Pump cradle inserts | four Ø4.0 ± 0.05 through-holes at (x −4.0, z −239.0), (x −4.0, z −171.0), (x 37.0, z −239.0), (x 37.0, z −171.0), offset ≤ 0.10, coaxial with OD-C03's holes as placed (U-03) | Hard | CAD | A-03 | `locate_bore` | A-03 |
| REQ-04 | Bulkhead inserts | four Ø4.0 ± 0.05 through-holes at (x 65.0, z −45.0), (65.0, −105.0), (65.0, −165.0), (65.0, −225.0), offset ≤ 0.10 | Hard | CAD | A-04 | `locate_bore` | A-04 |
| REQ-05 | Feet holes | four Ø3.4 ± 0.1 through-holes at (x ±110.0, z +90.0) and (x ±110.0, z −295.0), offset ≤ 0.10 | Hard | CAD | A-12 | `locate_bore` | A-12 |
| REQ-06 | Drain holes | two Ø8.0 ± 0.1 through-holes at (x −80.0, z −120.0) and (x −80.0, z −230.0), offset ≤ 0.10 | Hard | CAD | A-13 | `locate_bore` | A-13 |
| REQ-07 | Floor plane | the top face at y = 0.00 ± 0.10 (`envelope` max_y), 6.0 ± 0.1 thick; the whole top face one plane (the mounts' feet seat on it) | Hard | CAD | A-01 … A-03 | `envelope`; reviewer from sections | — |
| REQ-08 | Thermoblock zone | OD-H11 as placed: `envelope` max_z ≤ −85.0 and `clearance(plate, OD-H11)` ≥ 10.0 (OD-C05 A-05, OD-C04 REQ-01) | Hard | CAD | client (INTAKE X-20, X-30) | `envelope`, `clearance` | A-02 |
| REQ-10 | Valve mount inserts | four Ø4.0 ± 0.05 through-holes at (x −113.0, z −42.0), (x −71.0, z −42.0), (x −113.0, z −148.5), (x −71.0, z −148.5), offset ≤ 0.10, coaxial with OD-C07's footprint holes as placed by A-17 (checked against the OD-C07 STEP when it delivers; until then against the pattern) | Hard | CAD | A-17 | `locate_bore` | A-17 |
| REQ-11 | Tray inserts | four Ø4.0 ± 0.05 through-holes at (x 88.0, z −222.0), (106.0, −222.0), (88.0, −78.0), (106.0, −78.0), offset ≤ 0.10, coaxial with OD-C08's flange holes at the identity (U-03); each ≥ 6.0 centre to centre from every other hole, ≥ 8.0 from the plate edge | Hard | CAD | A-18 | `locate_bore` | A-18 |
| REQ-12 | Back panel inserts | four Ø4.0 ± 0.05 through-holes at (x ±81.0, z −282.0) and (x ±95.0, z −282.0), offset ≤ 0.10, coaxial with OD-C11's flange holes at the identity (U-03); ≥ 8.0 from the plate edge | Hard | CAD | A-18 | `locate_bore` | A-18 |
| REQ-13 | Side-panel bracket inserts | six Ø4.0 ± 0.05 through-holes at (x ±104.5, z −262.0), (±104.5, −15.0), (±104.5, +62.0), offset ≤ 0.10, coaxial with the OD-C16 brackets' screw holes as placed (U-03); ≥ 8.0 from the plate edge, ≥ 6.0 centre to centre from every other hole | Hard | CAD | A-19 | `locate_bore` | A-19 |
| REQ-14 | Front panel inserts | four Ø4.0 ± 0.05 through-holes at (x ±85.0, z +77.0) and (x ±95.0, z +77.0), offset ≤ 0.10, coaxial with OD-C09's flange holes at the identity (U-03); ≥ 8.0 from the plate edge, ≥ 6.0 centre to centre from every other hole | Hard | CAD | A-20 | `locate_bore` | A-20 |
| REQ-09 | Flatness in service | **Soft.** The printed plate stays flat enough for the three mounts to seat without rocking after printing and in use (warp on a 405 mm plate; PLA for now); not a geometric gate: the review reports it INCONCLUSIVE with a risk rating, and it is answered by the first print | Soft | part | client | — (bench) | A-10, A-14 |

**Named exceptions** (Usta U-18): none.

## §6 Assumptions ledger

| ID | Question | Current assumption | Risk if wrong | Source of the value | Retire by | Status |
|---|---|---|---|---|---|---|
| A-01 | OD-C05 carrier joint and height | the carrier's (= housing's) frame mapped by x → X, y → +Z, z → −Y with its origin at (0, 180.06, 32.0): the group head axis vertical, the mouth down (1.2, OD-C05 spec 2.0 A-02, RV01 F1); its foot underside at its z +180.06 on y 0; its holes at (±35, z −40 / −60) as OD-C05 spec §4 (the pattern of spec 1.x kept); the housing's rear face at y 205, the spouts at y ≈ 135.2 (OD-C05 A-03); the carrier is not built yet: the check assembly uses its foot outline box (x ±55, z −70 … −26) and the OD-G01 v02 STEP at the housing's pose | the carrier does not seat or its holes miss; the group head height changes | OD-C05 spec 2.0 §2, A-02 … A-04; this spec | OD-C05's delivered build; the Usta's answer to the up-direction card | OPEN |
| A-02 | OD-C04 joint | identity rotation, origin (0, 70, −140): the thermoblock's axis horizontal at y ≈ 55.9 (its axis at its y −14.13), pipes and terminals up, outlet pins at z −89.21 toward the group head, casting ≥ 16.5 above the plate (OD-C04 A-07, A-10) | the thermoblock fouls the carrier or the tube runs do not reach | OD-C04 spec 1.2 §2, A-07, A-10 (INTAKE X-12 … X-22); this spec (P4) | the Usta's layout confirmation; the tube runs | OPEN |
| A-03 | OD-C03 joint | rotation local x → +Z, y → −Y, z → +X, origin (0, 40, −205): pump axis along X at y 40 across the back, the terminal block (its −Y) up, the outlet (its −Z) toward −X where the valves sit; its foot 8 mm behind the thermoblock mount's foot | pump hoses do not reach; vibration path | OD-C03 spec 1.2 §2, A-08 (INTAKE X-01 … X-11); this spec | the Usta's layout confirmation; the tube runs | OPEN |
| A-04 | OD-C02 bulkhead interface | a wall on the plane x = 65 from z −240 to −30 (3 to 5 thick), standing on four M3 inserts at (65, −45), (65, −105), (65, −165), (65, −225); the electric zone is x ≥ 70 | OD-C02 must be designed to it | this spec (design choice; the OD-C03/C04/C05 precedent) | OD-C02 design | OPEN |
| A-05 | Valve and flowmeter zone | OD-C07 with OD-H21, OD-H22, OD-H24 within x −117 … −67, z −154 … −35, on the pump's outlet side, placed by A-17 (1.1) | the zone is too small or on the wrong side of the tube runs | this spec; WATER_FLOW.md (INTAKE §3) | OD-C07 design | OPEN |
| A-06 | Drip tray | the tray OD-C21 with its grid stands on the plate within x ±75, z −15 … +85, under the mouth at (0, 32), its cup rest top ≤ 36.9 above the plate (so the portafilter spouts at y ≈ 135.2 keep the ≥ 95 mm mug rule, INTAKE X-29, X-43; OD-C05 A-03); no locating features until the scan | the mug does not fit or the tray hangs over the edge | this spec; issue #9 (INTAKE X-57) | the tray scan (issue #9) | OPEN |
| A-07 | Water tank zone | OD-W01 with its dock OD-C06 stands within x ±70, z −305 … −250, lifted out upward; the tank seat OD-W03 faces the pump | the tank does not fit; the plate must grow | this spec; BOM OD-W01, OD-C06 (INTAKE §3) | the tank scan; OD-C06 design | OPEN |
| A-08 | Electronics bay | OD-C08 (path 1, the OEM PCB OD-E01; delivered) occupies x 73 … 112, z −230 … −70, y 0 … 92 inside the bay x 70 … 120, z −240 … −30 | the bay is too small | this spec; OD-C08 integration notes 2026-10-01 | OD-C08 print and fit | OPEN |
| A-09 | Kobra Max 3 build volume | 420 × 420 × 500 (Anycubic specification, not in the machine file); the plate is 240 × 405 flat | plate does not fit: C3 (two halves) | memory of the spec sheet (as OD-C03 A-10) | the Usta reads the printer | OPEN |
| A-10 | Material | PLA for now (the Usta, 2026-10-02), density 1240 kg/m³, on the Kobra Max 3; the service material (PETG or ASA) is still open | creep under the tank, softening near 60 °C (the plate is ≥ 16.5 below the thermoblock) | BOM OD-C01 (INTAKE §3); SOURCING_GUIDE §6 rule 3 | the Usta names the filament | OPEN |
| A-11 | Insert | M3 × 5.7 × Ø4.6 heat-set inserts in Ø4.0 through-holes of the 6.0 plate, driven from the top (OD-G01 A-17's figure); the screw tips may reach 0.3 below the plate | insert pulls out; the plate needs bosses | this spec; INTAKE §3 (OD-F01) | the Usta's stocked insert datasheet | OPEN |
| A-12 | Feet | four printed feet OD-C15 (or the OEM pads OD-C25/C26), each held by an M3 × 12 from the plate top through the Ø3.4 holes at (±110, +90) and (±110, −295) into a nut captive in the foot (OD-C15 A-02, 1.3; supersedes "screwed from below into inserts of the feet"); a Ø8 × 2 keep-out above each hole for the screw head | feet option changes; holes move | this spec; BOM OD-C15, C25, C26 (INTAKE X-44, X-68 … X-71) | the Usta picks the feet | OPEN |
| A-13 | Drainage | two Ø8 drain holes in the wet zone let a leak leave the machine onto the counter under it; the tray zone drains by the tray; no channels on the flat plate (C2 later) | a leak reaches the electronics before a drain | this spec; SOURCING_GUIDE §6 rule 1 (INTAKE X-41) | OD-C02's drainage path | OPEN |
| A-14 | Print orientation | flat on the bed, bottom face down, no supports, brim against warp | warp lifts the corners (REQ-09) | this spec | first print | OPEN |
| A-15 | Scan fidelity of the OEM parts | OD-H01 p95 0.448 and OD-H11 p95 0.474 (INTAKE X-08, X-19, §4 gap 13); the mounts' hole patterns are design values, not scan values, so only the placed OEM envelopes carry the scan error | the thermoblock zone or the pump reach is off by the scan error | the mounts' specs | calipers | OPEN |
| A-17 | OD-C07 joint and footprint | OD-C07 (spec at RV01 REVISE, not yet approved) needs four M3 inserts at its (−18, ±21) and (88.5, ±21) (its A-14, REQ-06), its bottom face on the floor; placed by the joint of §4 (x → −Z, y → −X, z → +Y, origin (−92, 0, −60)): holes at (−113, −42), (−71, −42), (−113, −148.5), (−71, −148.5), web to the plate edge 5.0 | the pattern or the pose changes when OD-C07 is approved; the holes move | OD-C07 spec A-14 (relayed from the "Chassis parts C06 to C11" thread, 2026-09-30); this spec (pose: design choice) | OD-C07's approved build and its delivered STEP | OPEN |
| A-18 | OD-C08 and OD-C11 joints | both modelled in the machine frame, placed at the identity: OD-C08's flange and OD-C11's floor flanges stand on y 0; their holes as REQ-11 and REQ-12; their reviewers found the plate solid under each (≥ 6 from every existing hole, ≥ 8 from the edge) | the parts move and the holes miss | OD-C08 and OD-C11 integration notes (2026-10-01) | their first print and fit | OPEN |
| A-19 | OD-C16 bracket joints | the bracket (its frame: block x −19 … 0, y 0 … 16, z ±8) placed on the right side by translation (117, 0, z_c), on the left by a 180° rotation about Y then (−117, 0, z_c), z_c ∈ {−262, −15, +62}; its screw hole lands on (±104.5, z_c) | the panels move and the holes miss | OD-C12/C13/C16 integration notes (2026-10-02), side spec A-01, REQ-06 | the first print and fit | OPEN |
| A-20 | OD-C09 joint | modelled in the machine frame, placed at the identity; its floor flanges (z +72 … +94) on y 0, holes as REQ-14, 19.8 from the feet holes at (±110, +90) and 17.8 from the bracket inserts at (±104.5, +62) | the panel moves and the holes miss | OD-C09/T01 integration notes (2026-10-03), C09 spec A-01, REQ-01 | the first print and fit | OPEN |
| A-16 | Footprint and height | 240 × 405 plate; machine height ≈ 260 (plate 6 + axis 175 + housing 43.1 + top panel and clearance) plus feet; the thesis' 0.4 m³ figure (INTAKE X-53) is read as an upper bound the machine is far below | the machine is too big for the Usta's counter | this spec | the Usta's layout confirmation | OPEN |

## §7 Decisions

| Date | Decision | By | Ref |
|---|---|---|---|
| 2026-09-30 | job opened at PUBLIC on the Usta's "go" after OD-C03 and OD-C04; C1 proposed | Oğuz | job_start |
| 2026-09-30 | spec 1.0 ratified and C1 chosen on the Usta's standing instruction and "go" of 2026-09-30; the Usta confirms or amends §5 and §6 at the next opportunity, the layout of §4 above all | the Usta (standing instruction), recorded by Oğuz | usta_gate spec_ratified, concept_picked |
| 2026-09-30 | the drip tray blocker (chassis order-of-work row 7) is lifted on the Usta's "go": the tray is a reserved zone (A-06); the job is reopened when the scan lands | Oğuz on the Usta's "go" | REQUEST.md |
| 2026-09-30 | the group head axis goes to 175 above the floor (OD-C05 spec 1.1) so that a tray up to 36.9 tall fits under the ≥ 95 mm mug rule; OD-C05 spec 1.0's 150 left 11.9 | Oğuz | INTAKE §4 gap 4; A-01 |
| 2026-09-30 | INTAKE §4 gaps 1, 2, 11, 12 (frames, positions, floor planes, the thermoblock offset) are answered by the joints of §4 as design choices, all A-## rows | Oğuz | §4, A-01 … A-03 |
| 2026-09-30 | REQ-09 (flatness) is a Soft bench gate answered by the first print (the OD-C03 RV01 lesson) | Oğuz | §5 |
| 2026-09-30 | the group head axis is vertical with the mouth down (OD-C05 RV01 F1; put to the Usta as a decision card): the housing pose of §4 and A-01 rewritten, the tray zone moved under the mouth; the plate's holes and every other feature stand; the housing's rear face at y 205 from the portafilter spouts (OD-C05 spec 2.0 A-03) | Oğuz, on OD-C05 spec 2.0 | A-01, A-06 |
| 2026-09-30 | OD-C07's footprint (four inserts, 106.5 × 42) goes on the plate now (REQ-10, A-17) rather than as a later round: placed in the valve zone with the flowmeter to the front, the hose window over the drain at (−80, −120), 11 behind-clearance to the pump; the zone grows to x −117 … −67, z −154 … −35 | Oğuz, on the OD-C07 spec A-14 | A-05, A-17 |
| 2026-10-02 | revision B: eighteen Ø4.0 insert through-holes for OD-C08, OD-C11, the OD-C16 brackets and OD-C09 (REQ-11 … REQ-14, A-18 … A-20) in the plate's existing convention (through the 6.0 plate, insert from the top, as the other twenty); PLA for now (A-10); feet held from the top (A-12); every other feature of build v02 unchanged | Oğuz, on the Usta's 2026-10-02 answers and the C08/C11 integration notes | A-10, A-12, A-18 |

## §8 Change log

| Version | Date | Change |
|---|---|---|
| 0.1 | 2026-09-30 | first draft from the three mounts' specs and the OEM reports |
| 1.0 | 2026-09-30 | INTAKE_v01 cross-references in §6; ratified |
| 1.2 | 2026-09-30 | the group head vertical (OD-C05 spec 2.0): the housing pose in §4, U-03, A-01, A-06, the tray zone z −15 … +85; no change to the plate's features |
| 1.1 | 2026-09-30 | OD-C07 joint and four insert holes (§4, U-05, D-05b, J-05, REQ-10, A-05, A-17); twenty insert holes |
| 1.3 | 2026-10-02 | revision B: thirty-eight insert holes (§4, U-03, U-05, D-05b, J-05, REQ-11 … REQ-14, A-18 … A-20); PLA for now (§3, A-10); feet from the top (A-12); OD-C08 path 1 (A-08) |

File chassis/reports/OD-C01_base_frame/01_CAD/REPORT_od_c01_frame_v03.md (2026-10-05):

# REPORT — od_c01_frame v03 (20260930-od-c01-base-frame)

Designer: Claude Code, Opus 5 · spec version 1.3 · plan `01_CAD/DESIGN_PLAN.md` with the notes of briefs WP-03 and WP-04 and the amendments of brief WP-06 · brief WP-06 (J3, revision B, build attempt 1 of 2, fix_cycles 3) · 2026-10-05 UTC

Every number below was measured by `01_CAD/check_od_c01_frame_v03.py` on the re-imported STEP files `02_STEP_STL/od_c01_frame_C1_v03.step` and `02_STEP_STL/od_c01_assembly_C1_v03.step`. The full rows (568, each with measured value, margin, location and reason) are in `01_CAD/check_od_c01_frame_v03.json`; §3 gives each §5 row's governing (least-margin) sub-row. The five new input hashes of WP-06 were re-checked before the build: every one matches. The v01 and v02 files are untouched; v03 has its own scripts (`*_v03.py`), started from the v02 scripts and changed only where WP-06's amendments say.

## 1. Files

| File | SHA-256 | Note |
|---|---|---|
| `01_CAD/build_od_c01_frame_v03.py` | a4362d041c6b9d3a81eec3b5b9c30bf926e99a675303f4981be4abd2abe5db9c | parametric script (plate and check assembly), Algebra mode |
| `01_CAD/check_od_c01_frame_v03.py` | dd5443a9f53e3093f0b9829cb6d245e2d4c4b98f246578c0b075cfd43697d4ed | checks, written before the build (D3); the v02 script plus the spec 1.3 rows |
| `01_CAD/sections_od_c01_frame_v03.py` | 4a07abee31949ecbca5c480ca47a0ecc4a81c8cfa313f87cab8b64ed88c83992 | D6 sections |
| `01_CAD/sweep_od_c01_frame_v03.py` | 32dff3c0e0cca22e97ba414a63e2343e588ca33326e5a131bb7f27d0e5a3f741 | D7 sweep |
| `01_CAD/probe/probe_newparts_v03.py` | 2ce21957220abb63eca46531cc287f6b83e3eedf727a1ee07ef1468f2a5898ba | pre-build probe of the five new inputs as placed (not a gate) |
| `01_CAD/probe/probe_newparts_v03.json` | 63871224aac81215445c5d835d2d2b030a2dc135dddcf2b664de84f0abbcbdb7 | probe readings: validity, envelopes, Y-axis bores of the placed inputs |
| `01_CAD/build_record_v03.json` | 14578f5f82db4d6dfa67dc7fa3b182cfa0c69d3dab0b0cbe951909a010865467 | parameters, export hashes, placements |
| `01_CAD/check_od_c01_frame_v03.json` | 7f8fa24be207662026f7bc852ce2256e3bd286036899d51f6058b27a7a1119d4 | check results (568 rows, facts) |
| `01_CAD/check_od_c01_frame_v03.log` | 4a59ab539921f1a497353144ccfec6ea902829faea6750ec987bbbf848080821 | check console |
| `01_CAD/sections_v03.json` | d8918c006e9da6c26ac5721ed910194fbd20fce75a608d1f0c2bdb1fa976ee93 | section planes, cut areas, nothing_clipped |
| `01_CAD/sweep_v03/sweep_summary_v03.json` | dfa7b5270131c3ab10226f0f33a5659fe53e3ff339b884a15309ffcfee4a9867 | sweep: per-variant status, worst margin per gate row |
| `01_CAD/sweep_v03_run.log` | 0ff89c22200aabf77d22e8d4a57d0d01044ab7905a3c296a3df74f14e64d02bc | sweep console |
| `02_STEP_STL/od_c01_frame_C1_v03.step` | 87877a649306995965d4640f54cbf83c20715888b29eb057b18e2f2d2933d29b | AP242 (`tools.core.write_step`), one solid `od_c01_frame` |
| `02_STEP_STL/od_c01_assembly_C1_v03.step` | 44d2120be386438de18bc05f260043f49dbb9ae18ba7a4157fc553a0e56c4e74 | AP242 check assembly, 17 labelled solids (§5) |
| `02_STEP_STL/od_c01_frame_C1_v03.stl` | 34d24746c62a6e1220544ce465d2714aa8f3b9631e3bf08d18e69937616af963 | binary STL, `tools.core.write_stl` after clearing the triangulation; tolerance 0.01 mm / angular 0.20 rad; 11 676 triangles |
| `03_Sections/od_c01_frame_v03_top_z-40_carrier.png` | 0ffdd5a8db8e668da25944e00cb1927af09043addfe1bb4384f9d0b9883d8811 | z = -40.00 mm; cut 1392.00 mm²; nothing clipped (0) |
| `03_Sections/od_c01_frame_v03_top_z-148_c04.png` | 0693ecca7e582dfaaff3ad238987f4054b314bf57296bede62baced45087c6b6 | z = -148.00 mm; cut 1345.52 mm²; nothing clipped (0) |
| `03_Sections/od_c01_frame_v03_left_x37_c03.png` | ac99353f6fba109133214c9dd4b569b8f2fa0fe7808a7244cca539c39ffb6914 | x = 37.00 mm; cut 2382.00 mm²; nothing clipped (0) |
| `03_Sections/od_c01_frame_v03_left_x65_bulkhead.png` | b710ecbd27a57bb08fba112d071b0447474caac1b68ce5987470a005c2908650 | x = 65.00 mm; cut 2334.00 mm²; nothing clipped (0) |
| `03_Sections/od_c01_frame_v03_top_z-120_drain.png` | aba7a87f4f858f26bdcd077f2636ee5c98930c9e22370cb19fbb99fbe1ebb60c | z = -120.00 mm; cut 1392.00 mm²; nothing clipped (0) |
| `03_Sections/od_c01_frame_v03_top_z90_feet.png` | 3ca693901b367b58f4db43b24dd8231ff13df9bb86f3096e3e805181ac77bb26 | z = 90.00 mm; cut 1399.20 mm²; nothing clipped (0) |
| `03_Sections/od_c01_frame_v03_top_z-42_valve.png` | 62b18e2313115bcf28e8eebdae376b71f85501e9633ef03fa40496ce019d0758 | z = -42.00 mm; cut 1392.00 mm²; nothing clipped (0) |
| `03_Sections/od_c01_frame_v03_left_x-113_valve.png` | eea2934ba4efbe8404daa09a2f6fbcf36b521319415680fc0a8c0d4d97e8f9f0 | x = -113.00 mm; cut 2376.47 mm²; nothing clipped (0) |
| `03_Sections/od_c01_frame_v03_front_y-3_plan.png` | 7d6f599a34c0bbeee9f4012a6b815e575487de91e5ea2be222f154d43622bde7 | y = -3.00 mm; cut 96499.79 mm²; nothing clipped (0) |
| `03_Sections/od_c01_frame_v03_top_z-222_tray.png` | 2fd0be4476f99d1c5e9c9f53f4fc075d26bc96b8e85c0ba6320ee5eb6bf2fd31 | z = -222.00 mm; cut 1392.00 mm²; nothing clipped (0) |
| `03_Sections/od_c01_frame_v03_top_z-78_tray.png` | f1b37ade024371d3907c1c83256b022137f9177fdecdf8c7f1f7805a6f55ef3a | z = -78.00 mm; cut 1392.00 mm²; nothing clipped (0) |
| `03_Sections/od_c01_frame_v03_top_z-282_back.png` | df046b935f0e07c04eed32a043c4ea07d7f6e7796533ba06ab24d7e9a656847e | z = -282.00 mm; cut 1344.00 mm²; nothing clipped (0) |
| `03_Sections/od_c01_frame_v03_top_z77_front.png` | 1418afd62d03e83cf712612de9246f21f635363c62c8ae7765c51982847318ba | z = 77.00 mm; cut 1344.00 mm²; nothing clipped (0) |
| `03_Sections/od_c01_frame_v03_top_z62_bracket.png` | 8b717a71e9141a704ad122deb7adf9ea04eb25352086125246bc45b3ee3810a3 | z = 62.00 mm; cut 1392.00 mm²; nothing clipped (0) |
| `03_Sections/od_c01_frame_v03_left_x104.5_bracket.png` | 50bed4d6b8455b898069704953ad9b856259dea34e2452bc6e4bd1648f216afa | x = 104.50 mm; cut 2326.25 mm²; nothing clipped (0) |
| `03_Sections/od_c01_frame_v03_left_asm_x0.png` | 70c30fc569dba04d15c1a50a149cc844c3cbc0cedb0b17440f27cd797dae0611 | x = 0.00 mm; cut 9598.61 mm²; nothing clipped (0) |
| `03_Sections/od_c01_frame_v03_top_asm_z-148.png` | 2929204c12633513553169b939bef3ef7e435748aea764a8d8d9a2b44b7078e3 | z = -148.00 mm; cut 2534.19 mm²; nothing clipped (0) |
| `03_Sections/od_c01_frame_v03_left_asm_x37.png` | 7f12af3967d25e52c3c88980841a4c1a4e9497151b90669cf8595c419d97c607 | x = 37.00 mm; cut 7467.34 mm²; nothing clipped (0) |
| `03_Sections/od_c01_frame_v03_top_asm_z32_mouth.png` | 1f23645267dfadda1a6a93935d52058153399dd5cf57d84b1741da3668b0d9b4 | z = 32.00 mm; cut 2106.22 mm²; nothing clipped (0) |
| `03_Sections/od_c01_frame_v03_top_asm_z-222_tray.png` | 320ccc296297ec9af3b42fbbdb00e953ec5262430807ea93a43d1472ce90c23f | z = -222.00 mm; cut 3951.29 mm²; nothing clipped (0) |
| `03_Sections/od_c01_frame_v03_top_asm_z-282_back.png` | a19d71f522eb6fd7f8d7749fc59b21505e22c9e1b583f6d4abde22ab4c9432ce | z = -282.00 mm; cut 1545.60 mm²; nothing clipped (0) |
| `03_Sections/od_c01_frame_v03_top_asm_z77_front.png` | 975f75d72a2ad33d1d57180301c1523afa267d54a561658b65cd07f7948d749b | z = 77.00 mm; cut 1982.68 mm²; nothing clipped (0) |
| `03_Sections/od_c01_frame_v03_left_asm_x104.5_bracket.png` | 0d93703808c768959e4b3171f11bf89f58cb2667c251fe7eec832480481b8c40 | x = 104.50 mm; cut 4775.35 mm²; nothing clipped (0) |

The sweep exports (11 variants: plate STEP, assembly STEP, STL, build record, check results) are under `01_CAD/sweep_v03/<variant>/` and are not deliverables. The new cut areas agree with hand arithmetic from spec §4: z −222 and z −78 cut two Ø4.0 holes each, 240 × 6 − 2 × 4.0 × 6 = 1392.00; z −282 and z +77 cut four, 1440 − 96 = 1344.00; x 104.5 cuts the three bracket holes through their axes and the two OD-C08 holes at x 106 as 2.6458 chords: 2430 − 72 − 2 × 2.6458 × 6 = 2326.25.

## 2. Versions

Python 3.13.7 · build123d 0.11.1 · OCP (cadquery-ocp-novtk) 7.9.3.1.1 · ocpsvg 0.6.0 · numpy 2.5.3 · repo commit d60daa486a25b3d2b51cf68356b01f501c4c3873
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

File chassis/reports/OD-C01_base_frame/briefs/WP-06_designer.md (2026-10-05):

# WP-06 — designer brief, J3 package (build v03, spec 1.3, revision B)

Job: 20260930-od-c01-base-frame · data class PUBLIC · spec `00_Spec/DESIGN_SPEC.md` version 1.3 (ratified 2026-10-05) · concept C1 (chosen) · target `od_c01_frame_v03` · revision B · build attempt 1 of 2 (the Usta ordered this round: halt_decision another_round, 2026-10-05) · fix_cycles 3

## Package

A **J3 package**: run D3–D9 against the plan `01_CAD/DESIGN_PLAN.md` with the notes of
`briefs/WP-03_designer.md` and `briefs/WP-04_designer.md` (part of the plan) and the
amendments below. Build v02 (`01_CAD/REPORT_od_c01_frame_v02.md`, reviewed RV01
`APPROVED_ASSUMPTION_CONDITIONAL`) is the starting point: copy your v02 scripts to
`_v03` names, change only what the amendments name, keep everything else (outline,
thickness, the twenty existing insert holes, feet, drains, the OD-C03/C04/G01 joints).
Export into `02_STEP_STL/od_c01_frame_C1_v03.step`, `02_STEP_STL/od_c01_assembly_C1_v03.step`,
`02_STEP_STL/od_c01_frame_C1_v03.stl`; sections with `_v03`; the sweep into
`01_CAD/sweep_v03/`; results into `01_CAD/check_od_c01_frame_v03.json`; the REPORT
into `01_CAD/REPORT_od_c01_frame_v03.md`. Leave every v01 and v02 file as it is. The
3MF is the orchestrator's step (report the STL's triangle count, volume and bounding
box). Return the block your skill defines. At the fix-cycle cap, or when a hard gate
cannot be met, stop with the measured failure (D9).

## Plan amendments (spec 1.3, checked by the orchestrator)

| Plan row | Amendment |
|---|---|
| Insert holes | **thirty-eight** Ø4.0 through-holes along Y (insert from the top, the existing convention): the twenty of v02 plus eighteen new ones. OD-C08 tray (REQ-11, A-18): (x 88.0, z −222.0), (106.0, −222.0), (88.0, −78.0), (106.0, −78.0). OD-C11 back panel (REQ-12, A-18): (±81.0, −282.0), (±95.0, −282.0). OD-C16 side-panel brackets (REQ-13, A-19): (±104.5, −262.0), (±104.5, −15.0), (±104.5, +62.0). OD-C09 front panel (REQ-14, A-20): (±85.0, +77.0), (±95.0, +77.0). U-05: 38 Ø4.0 + 4 Ø3.4 + 2 Ø8.0 = 44 bores; D-05a, D-05b, J-05 on all thirty-eight |
| Hole spacing (REQ-11 … REQ-14) | report, for every new hole, the nearest centre-to-centre distance to any other hole (≥ 6.0) and the distance to the plate's outline including the R 10 corner arcs (≥ 8.0) |
| Top face area (U-05 census) | rederive for 44 holes |
| Check assembly (U-03, 1.3 additions) | add the delivered parts in `00_Spec/inputs/` at their poses: `OD-C08_electronics_bay_tray.step`, `OD-C11_back_panel.step` and `OD-C09_front_panel.step` at the identity (modelled in this frame); `OD-C16_corner_bracket.step` six times: right side translate (117, 0, z_c), left side rotate 180° about Y (x → −X, y → Y, z → −Z) then translate (−117, 0, z_c), z_c ∈ {−262, −15, +62}. For each: designed contact with the plate top `clearance = 0`, `interference ≤ 0` mm³ with the plate, and each of its Ø3.4 plate-facing holes coaxial with the plate's Ø4.0 hole, offset ≤ 0.20 (`locate_bore` on both solids). Also check `OD-C07_valve_flowmeter_mount.step` (now delivered) against REQ-10's four holes by the A-17 joint the same way, and report it |
| Material (§3, A-10) | PLA, density 1240 kg/m³, for the mass figure; no geometry change |
| Zones (reported, not gated) | as v02; the electronics zone now holds OD-C08 (x 73 … 112, z −230 … −70) |
| Everything else | as v02 |

Spec 1.3 changed §1, §2 (four new input rows), §3, §4, U-03, U-05, D-05b, J-05, REQ-11 … REQ-14, A-08, A-10, A-12, A-18 … A-20; read the spec, not this table, where they differ.

## Gate IDs to check (spec §5)

U-01 … U-08 (U-08 N/A), D-01a, D-01b, D-02, D-03a, D-03b, D-04a, D-05a, D-05b,
D-06a, D-07 (N/A), J-05, E-06 (N/A), REQ-01 … REQ-14 (REQ-09 Soft bench:
INCONCLUSIVE, say so); plus `exactly_one_solid`, `feature_census`,
`envelope_within_spec`.
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

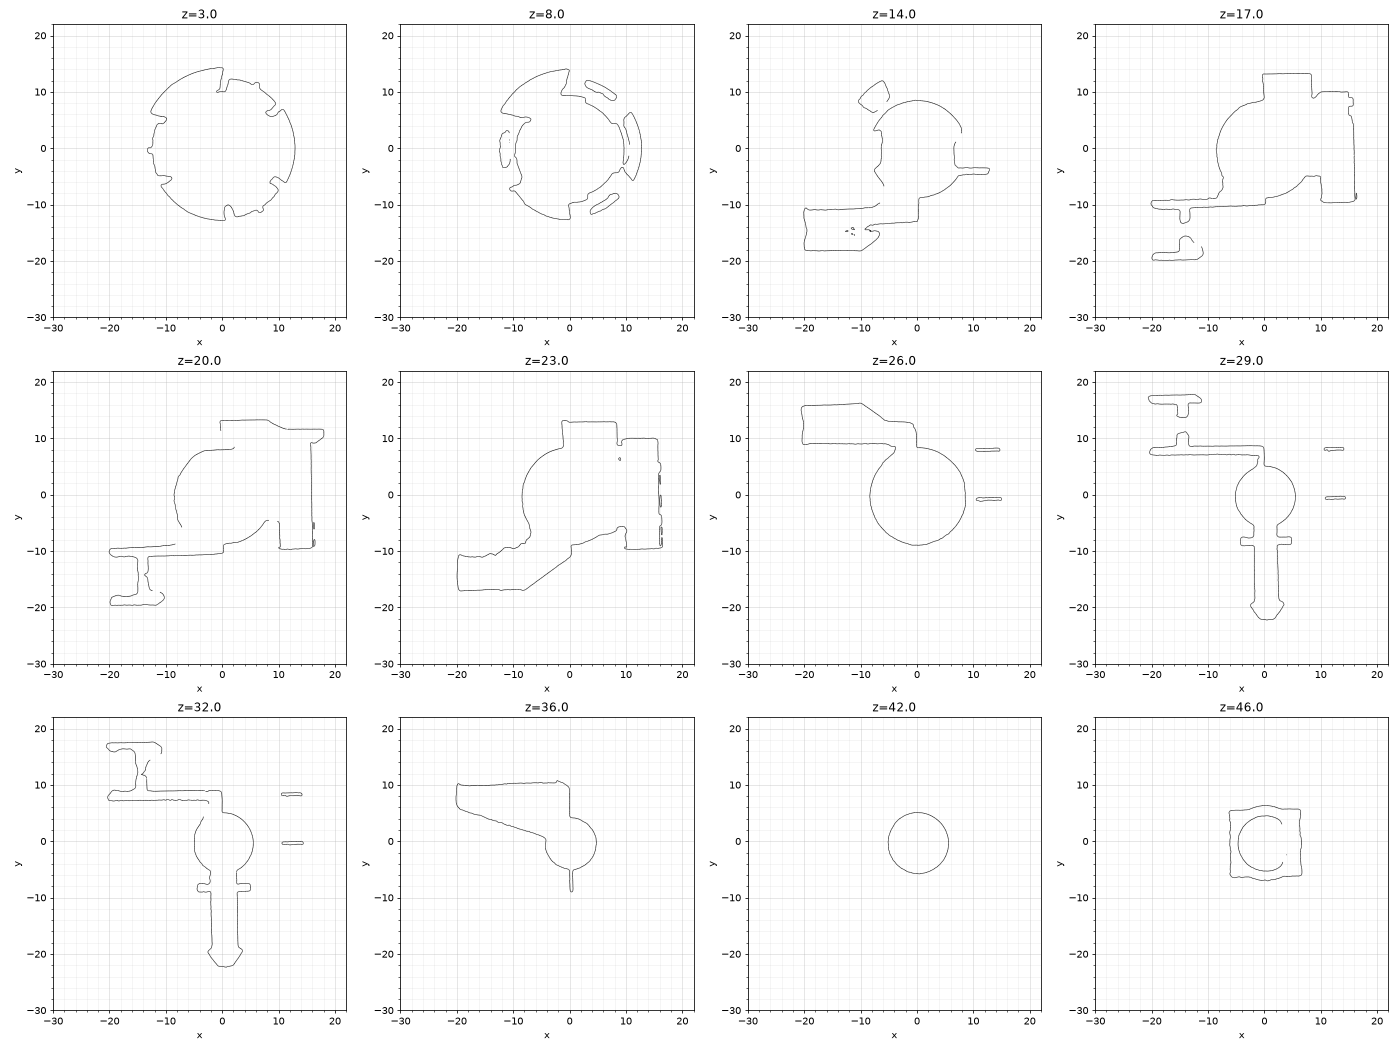
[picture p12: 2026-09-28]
step/reports/OD-S01_steam_valve/source/intake/figures/prov_sec_z2.png

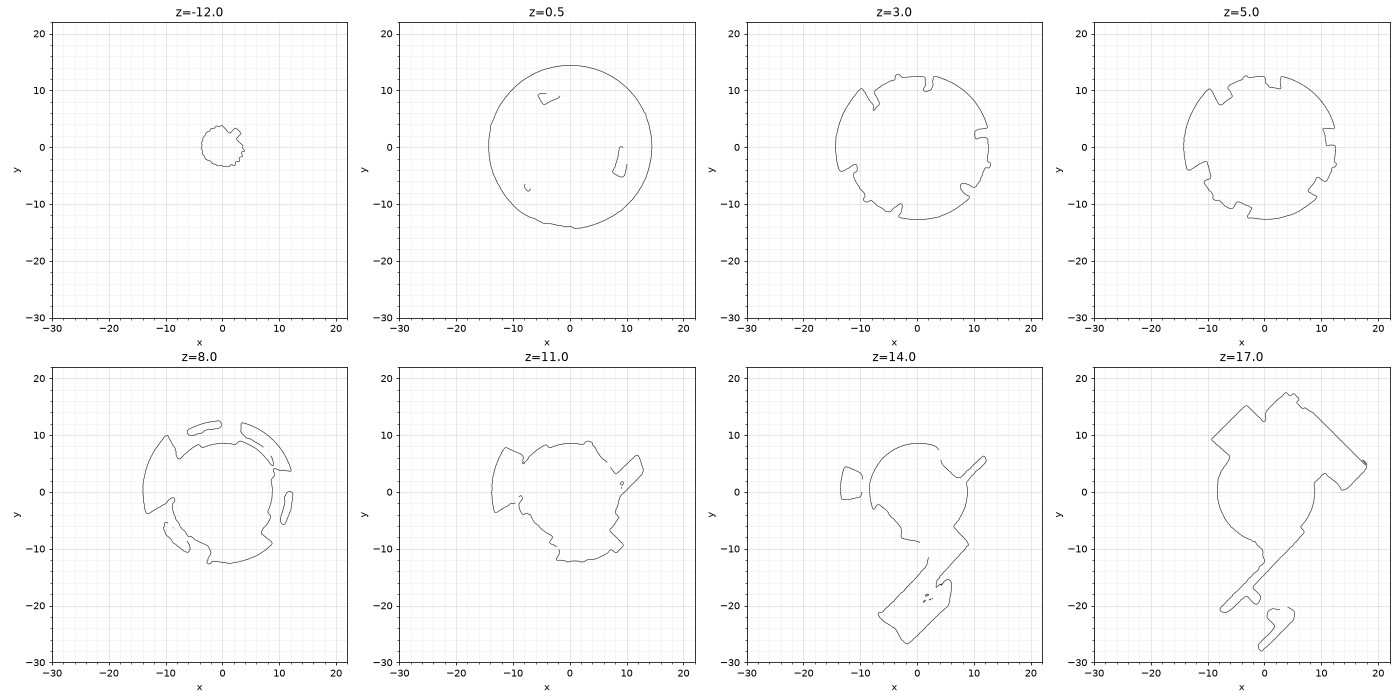
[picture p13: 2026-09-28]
step/reports/OD-S01_steam_valve/source/intake/figures/prov_sec_z1.png

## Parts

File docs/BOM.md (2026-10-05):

# Master BOM — Open Dedica (EC685 platform, 230 V build)

> **Generated from [`bom.csv`](bom.csv) by `tools/build_bom.py` — edit the CSV, not this file.**

Every part that appears in CAD, in a scan folder, or on the shopping list has a project **part number** `OD-Xnn`.
See [PART_NUMBERING.md](PART_NUMBERING.md) for the rules. Ref# / OEM code = De'Longhi EC885.M exploded view
(EC680/EC685 interchange on the wet side — verify by PNC before ordering). Prices are 2026 estimates in €.

**Type:** ASM assembly · OEM De'Longhi spare · PRINT our printed part · MFG our non-printed part ·
ELEC off-the-shelf electronics · STD standard hardware · REF reference only · FIX fixture/test rig
**CAD:** SCAN scan + parametric rebuild · CALIPER model from calipers · ENVELOPE simple placeholder solid ·
DESIGN native design · VENDOR vendor STEP
**Status:** ☐ todo · ✎ proposed · 📷 scanned · 🧊 modeled · ✅ validated (check-fixture) · ⏸ deferred

## Assembly tree

- `OD-000` Open Dedica espresso machine (top assembly)
  - `OD-H00` Hydraulic core
    - `OD-H10` Thermoblock sub-assembly
  - `OD-G00` Group head
    - `OD-G10` Portafilter 51 mm (filter holder assembly)
  - `OD-W00` Water path
    - `OD-W01` Water tank assembly
  - `OD-E00` Electronics (choose Path 1 OEM or Path 2 open controller)
  - `OD-C00` Chassis & body
    - `OD-C21` Drip tray (or printed replacement)
  - `OD-S00` Steam system (phase 2 — not in v1)

## OD-000 — Top assembly

| Part No | Parent | Type | Name | Ref# | OEM code | Qty | CAD | Material / spec | Source | ~€ | Issue | Status |
|---|---|---|---|---|---|---|---|---|---|---|---|---|
| `OD-000` |  | ASM | **Open Dedica espresso machine (top assembly)** |  |  | 1 | DESIGN |  |  |  |  | ☐ |

## H — Hydraulic core

| Part No | Parent | Type | Name | Ref# | OEM code | Qty | CAD | Material / spec | Source | ~€ | Issue | Status |
|---|---|---|---|---|---|---|---|---|---|---|---|---|
| `OD-H00` | OD-000 | ASM | **Hydraulic core** |  |  | 1 | DESIGN |  |  |  |  | ☐ |
| `OD-H01` | OD-H00 | OEM | Pump ULKA EP5/EX5 48 W 230 V 15 bar | 40 | AS00002825 | 1 | SCAN |  | AliExpress `ULKA EP5 48W 230V` / eBay / ulkapumps.com | 12–25 | #1 | 🧊 |
| `OD-H02` | OD-H00 | OEM | Pump protector (rubber sleeve) | 41 | 5213211161 | 1 | SCAN | rubber | AliExpress / FixPart | 4 | #1 | ☐ |
| `OD-H03` | OD-H00 | OEM | Pump suspension spring | 42 | 6113210761 | 1 | CALIPER | steel | FixPart / 4delonghi | 3 | #1 | ☐ |
| `OD-H10` | OD-H00 | ASM | **Thermoblock sub-assembly** |  |  | 1 | DESIGN |  |  |  | #2 | ☐ |
| `OD-H11` | OD-H10 | OEM | Thermoblock (generator 230 V 1300 W + plastic connector) | 60 | 5513226671 | 1 | SCAN | aluminium casting | AliExpress `EC680 thermoblock` / espressocoffeeshop | 25–40 | #2 | 🧊 |
| `OD-H12` | OD-H10 | OEM | Spacer | 61 | 5332239300 | 2 | CALIPER |  | 4delonghi | 3 |  | ☐ |
| `OD-H13` | OD-H10 | OEM | Generator gasket | 62 | 5313228791 | 2 (+2 spare) | CALIPER | rubber | 4delonghi | 3 |  | ☐ |
| `OD-H14` | OD-H10 | OEM | Connection | 67 | 5332242400 | 1 | CALIPER |  | 4delonghi | 3 |  | ☐ |
| `OD-H15` | OD-H10 | OEM | Right-angle generator connection | 70 | 5313218931 | 1 | CALIPER |  | 4delonghi | 4 |  | ☐ |
| `OD-H16` | OD-H10 | OEM | NTC sensor | 55 | 5217100200 | 1 | CALIPER |  | FixPart | 5 | #2 | ☐ |
| `OD-H17` | OD-H10 | OEM | NTC fixing bracket | 66 | 6113211071 | 1 | SCAN | steel | FixPart | 3 | #2 | ☐ |
| `OD-H18` | OD-H10 | OEM | TCO 192 °C thermal cutoff — **mandatory** | 68 | 511876 | 1 (+1 spare) | CALIPER |  | FixPart | 5 | #2 | ☐ |
| `OD-H19` | OD-H10 | OEM | TCO fixing bracket | 69 | 6013211951 | 1 | SCAN | steel | FixPart | 3 | #2 | ☐ |
| `OD-H21` | OD-H00 | OEM | Anti-drip valve | 39 | 7313260161 | 1 | SCAN |  | FixPart / 4delonghi | 5 | #41 | 🧊 |
| `OD-H22` | OD-H00 | OEM | 3-way valve | 43 | AS00004266 | 1 | SCAN |  | 4delonghi `valve BARM30E` | 5 | #6 | 🧊 |
| `OD-H23` | OD-H00 | OEM | 3-way valve connector | 75 | AS00005380 | 1 | CALIPER |  | 4delonghi | 3 | #6 | ☐ |
| `OD-H24` | OD-H00 | OEM | Flowmeter | 45 | 5213225251 | 1 | SCAN |  | FixPart / 4delonghi | 10–15 | #7 | 🧊 |
| `OD-H25` | OD-H00 | OEM | Flowmeter–pump tube | 37 | AS00005774 | 1 | ENVELOPE |  | FixPart | 4 |  | ☐ |

## G — Group head & portafilter

| Part No | Parent | Type | Name | Ref# | OEM code | Qty | CAD | Material / spec | Source | ~€ | Issue | Status |
|---|---|---|---|---|---|---|---|---|---|---|---|---|
| `OD-G00` | OD-000 | ASM | **Group head** |  |  | 1 | DESIGN |  |  |  | #3 | ☐ |
| `OD-G01` | OD-G00 | PRINT | Group head housing (open-source replacement for the molded OEM housing; strength untested until OD-T01) |  |  | 1 | DESIGN | PLA for now (fit-check prints only — hot zone; service ASA) | printed (Creality K1C) | print | #3 | 🧊 |
| `OD-G02` | OD-G00 | OEM | Brewing gasket | 46 | 537177 | 1 (+1 spare) | CALIPER | silicone | 4delonghi | 3 | #3 | ☐ |
| `OD-G03` | OD-G00 | OEM | Closure gasket | 47 | 5313221481 | 1 (+1 spare) | CALIPER |  | FixPart | 3 | #3 | ☐ |
| `OD-G04` | OD-G00 | OEM | Brewing gasket support | 48 | AS00005377 | 1 | SCAN |  | 4delonghi | 3 | #3 | 🧊 |
| `OD-G05` | OD-G00 | OEM | Bottom (diffuser) gasket | 49 | AS00005075 | 1 (+1 spare) | CALIPER |  | 4delonghi | 3 | #3 | ☐ |
| `OD-G06` | OD-G00 | OEM | Diffuser (shower screen) | 52 | 6013211191 | 1 | SCAN | stainless | 4delonghi | 3 | #3 | ☐ |
| `OD-G07` | OD-G00 | OEM | Connectors gasket | 54 | 5313237781 | 1 | CALIPER |  | FixPart | 3 | #3 | ☐ |
| `OD-G08` | OD-G00 | MFG | Group head face plate with portafilter lugs (optional upgrade) |  |  | 1 | DESIGN | aluminium / stainless (laser-cut or machined) | local shop | — |  | ✎ |
| `OD-G09` | OD-G00 | REF | OEM group head bayonet cup (molded into the case — reference geometry for OD-G01) |  |  | 0 | SCAN | molded plastic | donor | — | #38 | 🧊 |
| `OD-G10` | OD-G00 | OEM | Portafilter 51 mm (filter holder assembly) | 06 | AS00002706 | 1 | SCAN |  | OEM / AliExpress `51mm bottomless portafilter Dedica` | 20–30 | #39 | 🧊 |
| `OD-G11` | OD-G10 | OEM | Filter basket 1-cup | 03 | AS00003137 | 1 | CALIPER | stainless | OEM / aftermarket | 5 | #4 | ☐ |
| `OD-G12` | OD-G10 | OEM | Filter basket 2-cup | 04 | AS00003138 | 1 | CALIPER | stainless | OEM / aftermarket | 5 | #4 | ☐ |
| `OD-G13` | OD-G10 | OEM | ESE pods filter (optional) | 05 | 5513281011 | 1 | CALIPER |  | OEM | 5 |  | ☐ |

## W — Water path

| Part No | Parent | Type | Name | Ref# | OEM code | Qty | CAD | Material / spec | Source | ~€ | Issue | Status |
|---|---|---|---|---|---|---|---|---|---|---|---|---|
| `OD-W00` | OD-000 | ASM | **Water path** |  |  | 1 | DESIGN |  |  |  |  | ☐ |
| `OD-W01` | OD-W00 | OEM | Water tank assembly | 18 | 5513200359 | 1 | SCAN |  | FixPart / 4delonghi | 8–15 | #5 | ☐ |
| `OD-W02` | OD-W01 | OEM | Water tank | 32 | 7313285109 | 1 | SCAN |  | 4delonghi / FixPart | (in OD-W01) | #5 | ☐ |
| `OD-W03` | OD-W01 | OEM | Tray gasket (water tank seat — white seat with 2 barbed ports + black double gasket) | 30 | 5313236391 | 1 | SCAN |  | 4delonghi | 3 | #37 | 🧊 |
| `OD-W11` | OD-W00 | OEM | Tube L270 (tank → flowmeter) | 31 | 5313219841 | 1 | ENVELOPE | silicone | 4delonghi | 4 |  | ☐ |
| `OD-W12` | OD-W00 | OEM | Tube L150 | 33 | 5313236101 | 1 | ENVELOPE | silicone | FixPart | 4 |  | ☐ |
| `OD-W13` | OD-W00 | OEM | Tube with 2 bushes L230 | 71 | 7313285899 | 1 | ENVELOPE |  | 4delonghi | 5 |  | ☐ |
| `OD-W14` | OD-W00 | OEM | Tube with 1 bush L135 | 72 | 5513213661 | 1 | ENVELOPE |  | FixPart | 4 |  | ☐ |
| `OD-W15` | OD-W00 | OEM | PTFE tube with 2 bushes DI2-DE4 L100 | 73 | 5532111900 | 1 | ENVELOPE | PTFE | FixPart | 4 |  | ☐ |
| `OD-W21` | OD-W00 | OEM | Connector spring | 35 | 6132101300 | 4 | CALIPER | steel | 4delonghi | 8 (set) |  | ☐ |
| `OD-W22` | OD-W00 | OEM | O-ring D3.85 T2 | 36 | 5313217701 | 5 (+5 spare) | CALIPER | rubber | 4delonghi | 8 (set) |  | ☐ |
| `OD-W23` | OD-W00 | OEM | Clip (wire 1.2 AISI302) | 65 | 6113213191 | 3 | CALIPER | stainless | FixPart | 4 |  | ☐ |

## E — Electronics

| Part No | Parent | Type | Name | Ref# | OEM code | Qty | CAD | Material / spec | Source | ~€ | Issue | Status |
|---|---|---|---|---|---|---|---|---|---|---|---|---|
| `OD-E00` | OD-000 | ASM | **Electronics (choose Path 1 OEM or Path 2 open controller)** |  |  | 1 | DESIGN |  |  |  | #8 | ☐ |
| `OD-E01` | OD-E00 | OEM | Power PCB 230 V — Path 1 | 59 | AS00002829 | 1 | SCAN |  | AliExpress 4001101696035 / eBay | 35–45 | #33 | 🧊 |
| `OD-E02` | OD-E00 | OEM | Control board assembly (front buttons) — Path 1 | 15 | 7313285189 | 1 | SCAN |  | FixPart / eBay | 15–25 | #34 | 🧊 |
| `OD-E03` | OD-E00 | OEM | Microswitch | 16 | 5113210421 | 1 | CALIPER |  | FixPart | 4 | #8 | ☐ |
| `OD-E04` | OD-E00 | OEM | On/off push button | 28 | 5913216331 | 1 | CALIPER |  | FixPart | 3 |  | ☐ |
| `OD-E05` | OD-E00 | OEM | Unipolar switch 16 A 250 V | 29 | 5128109300 | 1 | CALIPER |  | FixPart | 4 |  | ☐ |
| `OD-E06` | OD-E00 | OEM | Power supply cord with plug (region-specific; AU code shown) | 53 | 5013276449 | 1 | ENVELOPE |  | FixPart / generic | 8 |  | ☐ |
| `OD-E07` | OD-E00 | OEM | 6-pole wiring | 56 | 5013211961 | 1 | ENVELOPE |  | FixPart | 10 (set) |  | ☐ |
| `OD-E08` | OD-E00 | OEM | Wiring with connectors | 57 | 5032509200 | 1 | ENVELOPE |  | FixPart | (set) |  | ☐ |
| `OD-E09` | OD-E00 | OEM | Wiring | 58 | 5013276049 | 1 | ENVELOPE |  | FixPart | (set) |  | ☐ |
| `OD-E51` | OD-E00 | ELEC | ESP32 dev board — Path 2 |  |  | 1 | VENDOR | 3.3 V WiFi | AliExpress | 5–10 |  | ☐ |
| `OD-E52` | OD-E00 | ELEC | SSR for heater — Path 2 |  |  | 1 | VENDOR | ≥25 A zero-cross mains-rated | RS / TME (no no-name for mains) | 8–15 |  | ☐ |
| `OD-E53` | OD-E00 | ELEC | Relay / SSR for pump — Path 2 |  |  | 1 | VENDOR | ≥2 A 230 V | RS / TME | 5–12 |  | ☐ |
| `OD-E54` | OD-E00 | ELEC | Thermocouple type K — Path 2 |  |  | 1 | ENVELOPE | glass-braid | Pimoroni / AliExpress | 20 (with OD-E55) |  | ☐ |
| `OD-E55` | OD-E00 | ELEC | MAX31855 thermocouple board — Path 2 |  |  | 1 | VENDOR |  | Pimoroni / AliExpress | (with OD-E54) |  | ☐ |
| `OD-E56` | OD-E00 | ELEC | Pressure transducer (optional) — Path 2 |  |  | 1 | VENDOR | 0–300 PSI G1/4 | per CaiJonas repo BOM | 15 |  | ☐ |
| `OD-E57` | OD-E00 | STD | G1/4 tee for pressure transducer (optional) |  |  | 1 | VENDOR | brass; 15 bar / 125 °C rated | hardware / AliExpress | 5 |  | ☐ |
| `OD-E58` | OD-E00 | ELEC | Logic PSU — Path 2 |  |  | 1 | VENDOR | 5 V or 24 V | Mean Well-style | 10 |  | ☐ |
| `OD-E59` | OD-E00 | MFG | SSR heat-sink plate |  |  | 1 | DESIGN | aluminium | local shop / scrap | — |  | ✎ |
| `OD-E60` | OD-E00 | STD | IEC inlet with fuse (alternative to OD-E06) |  |  | 1 | VENDOR |  | TME / AliExpress | 4 |  | ☐ |

## C — Chassis & body

| Part No | Parent | Type | Name | Ref# | OEM code | Qty | CAD | Material / spec | Source | ~€ | Issue | Status |
|---|---|---|---|---|---|---|---|---|---|---|---|---|
| `OD-C00` | OD-000 | ASM | **Chassis & body** |  |  | 1 | DESIGN |  |  |  |  | ☐ |
| `OD-C01` | OD-C00 | PRINT | Base frame / floor plate (revision B, 38 Ø4.0 insert holes) |  |  | 1 | DESIGN | PLA for now (service PETG or ASA: A-10) | printed (Anycubic Kobra Max 3) | print |  | 🧊 |
| `OD-C02` | OD-C00 | PRINT | Wet/electric bulkhead with drainage path |  |  | 1 | DESIGN | PLA for now (fit-check prints only — 13 from the thermoblock; service ASA) | printed (Creality K1C) | print |  | 🧊 |
| `OD-C03` | OD-C00 | PRINT | Pump cradle (sleeve + spring suspension) |  |  | 1 | DESIGN | PLA for now (service PETG) | printed | print | #1 | 🧊 |
| `OD-C04` | OD-C00 | PRINT | Thermoblock mount (≥10 mm air gap to printed walls) |  |  | 1 | DESIGN | PLA for now (fit-check prints only — hot zone; service ASA / PC) | printed | print | #2 | 🧊 |
| `OD-C05` | OD-C00 | PRINT | Group head carrier (ties OD-G00 to frame) |  |  | 1 | DESIGN | PLA for now (fit-check prints only — hot zone; service ASA) | printed (Creality K1C) | print | #3 | 🧊 |
| `OD-C06` | OD-C00 | PRINT | Water tank dock / inlet seat (deferred: the tank stands on the table; tubes leave through OD-C11) |  |  | 1 | DESIGN | PLA for now (service PETG) | printed | print | #5 | ⏸ |
| `OD-C07` | OD-C00 | PRINT | Valve & flowmeter mount (OPV reachable without disassembly) |  |  | 1 | DESIGN | PLA for now (service PETG) | printed | print | #6 | 🧊 |
| `OD-C08` | OD-C00 | PRINT | Electronics bay tray (holds the OEM power PCB OD-E01 on edge) |  |  | 1 | DESIGN | PLA for now (service PETG) | printed (Creality K1C) | print | #8 | 🧊 |
| `OD-C09` | OD-C00 | PRINT | Front panel with button bezel (3.0 wall, brew opening, OD-E02 on two bosses) |  |  | 1 | DESIGN | PLA for now (service ASA; ≈ 9 from the warm group head) | printed (Anycubic Kobra Max 3) | print | #8 | 🧊 |
| `OD-C10` | OD-C00 | PRINT | Top panel (removable — 4 screws) |  |  | 1 | DESIGN | PLA for now (service PETG) | printed (Anycubic Kobra Max 3) | print |  | 🧊 |
| `OD-C11` | OD-C00 | PRINT | Back panel (removable — 4 screws; cord and two tube pass-throughs; vents) |  |  | 1 | DESIGN | PLA for now (service PETG) | printed (Anycubic Kobra Max 3) | print |  | 🧊 |
| `OD-C12` | OD-C00 | PRINT | Left side panel (printed, 3.0 wall, lid lip, relief over OD-C07) |  |  | 1 | DESIGN | PLA for now (service ASA / PETG; no geometry change) | printed (Anycubic Kobra Max 3) | print |  | 🧊 |
| `OD-C13` | OD-C00 | PRINT | Right side panel (printed, 3.0 wall, lid lip) |  |  | 1 | DESIGN | PLA for now (service ASA / PETG; no geometry change) | printed (Anycubic Kobra Max 3) | print |  | 🧊 |
| `OD-C14` | OD-C00 | PRINT | Cord grommet, split half (two per grommet, closed by a cable tie) |  |  | 2 | DESIGN | PLA for now (service TPU) | printed (Creality K1C) | print |  | 🧊 |
| `OD-C15` | OD-C00 | PRINT | Foot (TPU, Ø18 × 10, captive M3 nut; alternative to OD-C25/C26) |  |  | 4 | DESIGN | PLA for now (service TPU 95A: A-03) | printed (Creality K1C) | print |  | 🧊 |
| `OD-C16` | OD-C00 | PRINT | Side panel corner bracket (3 per side) |  |  | 6 | DESIGN | PLA for now (service ASA / PETG) | printed (Creality K1C) | print |  | 🧊 |
| `OD-C21` | OD-C00 | OEM | Drip tray (or printed replacement) | 09 | 5313249971 | 1 | SCAN |  | FixPart / printed | 8–12 | #9 | ☐ |
| `OD-C22` | OD-C21 | OEM | Float | 08 | 5313249981 | 1 | SCAN |  | FixPart | (with OD-C21) | #9 | ☐ |
| `OD-C23` | OD-C00 | OEM | Cup holder | 07 | 6013214801 | 1 | CALIPER |  | FixPart / printed | 5 | #9 | ☐ |
| `OD-C24` | OD-C00 | OEM | Cup holder with frame | 12 | 5513226761 | 1 | CALIPER |  | FixPart / printed | (with OD-C23) | #9 | ☐ |
| `OD-C25` | OD-C00 | OEM | Rubber foot pad | 34 | 5313229381 | 2 | CALIPER | rubber | FixPart | 4 (set) |  | ☐ |
| `OD-C26` | OD-C00 | OEM | Rubber foot pad | 76 | 5313274719 | 2 | CALIPER | rubber | FixPart | (set) |  | ☐ |

## F — Fasteners, standard hardware & consumables

| Part No | Parent | Type | Name | Ref# | OEM code | Qty | CAD | Material / spec | Source | ~€ | Issue | Status |
|---|---|---|---|---|---|---|---|---|---|---|---|---|
| `OD-F01` | OD-000 | STD | M3 heat-set insert (Ø4.0 bore × 6; 58 in the chassis: 34 in OD-C01 rev B; BUILD_GUIDE §5) |  |  | ~70 | VENDOR | brass M3 | AliExpress | 10 (set) |  | ☐ |
| `OD-F02` | OD-000 | STD | M3×8 screw |  |  | ~65 | VENDOR | ISO 7380 / DIN 912 A2 | AliExpress | (set) |  | ☐ |
| `OD-F03` | OD-000 | STD | Acrylic sheet 3 mm (optional skins; not used: the side panels are printed) |  |  | per design | — | PMMA | local laser / leftover stock | 25 |  | ⏸ |
| `OD-F04` | OD-000 | STD | Food-safe silicone tube 4×2 mm (routing reserve) |  |  | 1 m | ENVELOPE | silicone | AliExpress | 5 |  | ☐ |
| `OD-F05` | OD-000 | STD | High-temp epoxy (steam port blank) |  |  | 1 | — | 125 °C / 15 bar | hardware store | 8 |  | ☐ |
| `OD-F06` | OD-000 | STD | 6.3 mm insulated spade terminals + 105 °C wire (own looms) |  |  | 1 set | — |  | TME / AliExpress | 5 |  | ☐ |
| `OD-F07` | OD-000 | STD | Metal spacer Ø7 × 10.10 mm (Ø4 bore; OD-C04 thermoblock stand-off) |  |  | 1 | — | steel / brass tube cut to length (+0.10/−0) | local shop / scrap | 1 | #2 | ☐ |
| `OD-F08` | OD-000 | STD | Metal spacer Ø7 × 37.70 mm (Ø4 bore; OD-C04 thermoblock stand-off) |  |  | 1 | — | steel / brass tube cut to length (+0.10/−0) | local shop / scrap | 1 | #2 | ☐ |
| `OD-F09` | OD-000 | STD | Cable tie 4.8 mm (OD-C03 pump strap; OD-C14 grommet) |  |  | 3 | VENDOR | PA66 UV-black | hardware store | 1 | #1 | ☐ |
| `OD-F10` | OD-000 | STD | M3×12 screw (OD-C01 into the OD-C02 base rail; tip ends on the bore floor; and the four OD-C15 feet from the plate top) |  |  | 8 | VENDOR | ISO 7380 / DIN 912 A2 | AliExpress | (set) |  | ☐ |
| `OD-F11` | OD-000 | STD | M3×6 screw (OD-E01 board holes H1/H2 into the OD-C08 standoffs; M3×8 only with a ≥ 0.5 washer) |  |  | 2 | VENDOR | ISO 7380 / DIN 912 A2 | AliExpress | (set) | #8 | ☐ |
| `OD-F12` | OD-000 | STD | M3 hex nut (captive in the OD-C15 feet; nylon-insert ISO 10511 needs M3×16) |  |  | 4 | VENDOR | ISO 4032 A2 | AliExpress | (set) |  | ☐ |
| `OD-F13` | OD-000 | STD | M3×18 screw (OD-E02 board into the OD-C09 bosses from the board's back) |  |  | 2 | VENDOR | ISO 4762 / DIN 912 A2 | AliExpress | (set) | #8 | ☐ |
| `OD-F14` | OD-000 | STD | M3×10 screw (OD-T01 plate into the OD-G01 housing inserts; bench fixture only) |  |  | 4 | VENDOR | ISO 7380 A2 | AliExpress | (set) | #3 | ☐ |
| `OD-F15` | OD-000 | STD | Cable tie 2.5 mm (OD-C08 loom slots 2.0 × 4.0; a 4.8 mm tie does not pass) |  |  | 2 | VENDOR | PA66 | hardware store | 1 | #8 | ☐ |
| `OD-F16` | OD-000 | STD | Self-tapping screw Ø3.5 (OD-C04 into the thermoblock: S1 ≈ 22, S2 ≈ 50 long; OD-C04 A-04, measure the OEM screws) |  |  | 2 | VENDOR | steel A2 | from the donor / hardware store | 1 | #2 | ☐ |

## S — Steam system (phase 2)

| Part No | Parent | Type | Name | Ref# | OEM code | Qty | CAD | Material / spec | Source | ~€ | Issue | Status |
|---|---|---|---|---|---|---|---|---|---|---|---|---|
| `OD-S00` | OD-000 | ASM | **Steam system (phase 2 — not in v1)** |  |  | 1 | DESIGN |  |  |  |  | ⏸ |
| `OD-S01` | OD-S00 | OEM | Steam valve assembly | 17 | AS00002707 | 1 | SCAN |  | FixPart | 15 | #35 | 🧊 |
| `OD-S02` | OD-S00 | OEM | Steam hose assembly (steam wand — scanned together with nozzle OD-S04) | 10 | AS00002705 | 1 | SCAN |  | FixPart | 12 | #36 | 🧊 |
| `OD-S03` | OD-S00 | OEM | Steam knob | 13 | 7313285479 | 1 | SCAN |  | FixPart | 6 | #31 | 🧊 |
| `OD-S04` | OD-S00 | OEM | Nozzle | 77 | AS00002710 | 1 | CALIPER |  | FixPart | 5 |  | ⏸ |
| `OD-S05` | OD-S00 | OEM | Dispenser cover | 11 | 5313237931 | 1 | CALIPER |  | FixPart | 4 |  | ⏸ |
| `OD-S06` | OD-S00 | OEM | Steam valve bracket |  |  | 1 | SCAN |  | donor |  |  | ⏸ |

## R — OEM parts not used (reference only)

| Part No | Parent | Type | Name | Ref# | OEM code | Qty | CAD | Material / spec | Source | ~€ | Issue | Status |
|---|---|---|---|---|---|---|---|---|---|---|---|---|
| `OD-R01` |  | REF | Upper cover (OEM case — reference only) | 01 | 7313285179 | 0 | — |  | donor | — |  | — |
| `OD-R02` |  | REF | Left profile (OEM case — reference only) | 19 | 5313251321 | 0 | — |  | donor | — |  | — |
| `OD-R03` |  | REF | Right profile (OEM case — reference only) | 26 | 5313251311 | 0 | — |  | donor | — |  | — |
| `OD-R04` |  | REF | Coffee measuring spoon (accessory) | 02 | 7313286119 | 0 | — |  | donor | — |  | — |
| `OD-R05` |  | REF | Cleaning tool (accessory) | 000 | AS00003850 | 0 | — |  | donor | — |  | — |
| `OD-R06` |  | REF | Ecomulticlean 10 ml vial (accessory) | 000 | AS00000378 | 0 | — |  | donor | — |  | — |

## T — Test fixtures & rigs

| Part No | Parent | Type | Name | Ref# | OEM code | Qty | CAD | Material / spec | Source | ~€ | Issue | Status |
|---|---|---|---|---|---|---|---|---|---|---|---|---|
| `OD-T01` |  | FIX | Group head bench pressure-test rig (M1 close-out; 25 mm plate; procedure in chassis/OD-T01_TEST_PROCEDURE.md) |  |  | 1 | DESIGN | PLA (100 % infill; cold water only) | printed (Anycubic Kobra Max 3) + fittings (see the test procedure) | — | #3 | 🧊 |

## Budget summary (230 V, no donor)

| Block | Estimate |
|---|---|
| H Hydraulic core | €85–120 |
| G Group head + portafilter | €45–60 |
| W Water path | €50 |
| E Electronics (either path) | €60–100 |
| C/F Chassis hardware | €50 |
| **Total (all new parts)** | **€290–380** |
| **Donor-machine route** (broken EC685 €50 + wear kit €40 + chassis €50) | **~€140** |

Thesis reference total (2019, all-new UK spares): £295.

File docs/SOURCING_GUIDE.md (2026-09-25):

# How to Source the BOM for an Open-Source DIY De'Longhi Dedica Espresso Machine

*A component-sourcing and reverse-engineering guide for building a custom 3D-printed-chassis espresso machine around genuine De'Longhi Dedica EC685 internals.*

> **Caution — this guide may contain errors and omissions.** Part numbers, prices and links change constantly. We have no relation to any of the sellers linked in this guide — links are provided to verify our findings and to seed your own searches.

> **⚡ SAFETY: This machine runs on mains voltage (230 V or 120 V), heats water to ~125 °C, and pressurizes it to 15 bar.** Anything you build must keep the wet side separated from the electric side, use properly rated wiring and crimps, keep the 192 °C thermal cutoff (TCO) in circuit, and be tested behind an RCD/GFCI. Never print load-bearing or heat-adjacent parts in PLA.

---

## 1. The Concept

The De'Longhi Dedica EC685 is one of the best-value semi-automatic espresso platforms ever made: a 1300 W single-part thermoblock, a genuine ULKA 15-bar vibratory pump, a proper 51 mm portafilter, and a compact plumbing layout — all of whose internal parts are **publicly purchasable as spares**. This was proven by Zack Moss's 2019 MEng thesis *Open Source Espresso Machine for Makers*, which reverse-engineered exactly this machine (EC685.M), rebuilt it around Arduinos, and matched the original in temperature stability and espresso taste.

The one component you **cannot** buy is the chassis-integrated group head housing — De'Longhi molded it into the case. The thesis solved this with a 3D-printed ABS housing holding the genuine gaskets and diffuser. That is our opening: if the group head housing must be printed anyway, the **entire chassis** can be an open-source 3D-printed design.

**The plan:**
1. Source every functional Dedica part (pump, thermoblock, valves, tubes, tank, portafilter, PCB or open controller).
2. 3D-scan / measure each part and produce a STEP file library.
3. Design an open, printable chassis in CAD around the STEP assembly.
4. Publish BOM + STEP + STL/3MF + build instructions.

This mirrors the approach of the [OOMWOO open-source vacuum robot BOM guide](https://makerspet.com/blog/how-to-source-bom-for-oomwoo-open-source-vacuum-robot/): salvage/source proven mass-produced components, print everything structural.

---

## 2. Two Sourcing Strategies

### Strategy A — Donor machine (recommended)
Buy a **used, broken, or open-box Dedica EC680 / EC685 / EC885** and strip it. A defective unit sells for €30–70 on eBay/Kleinanzeigen/Marktplaats/local classifieds; even a new one (~€120–150) is cheaper than buying every part individually (the thesis parts list totalled **£295** buying parts one by one, and called the De'Longhi spares "very overpriced"). Most "broken" Dedicas have a scaled thermoblock, a torn brew gasket, or a dead pump — each a €10–25 fix — while every other part is a free spare.

- eBay search seeds: `Dedica EC685 defekt`, `Dedica EC685 parts repair`, `EC680 faulty`
- What kills them: limescale blockage (recoverable — descale/replace tubes), pump failure (€15), leaking group gasket (€3).

### Strategy B — All-new parts
Buy every component as a spare. Slower and pricier, but every part is new and you get exact BOM traceability. Use the part-code tables below. Best hybrid: donor machine for the plumbing + new wear parts (gaskets, O-rings, brew gasket, tubes).

**⚠ Voltage:** EC685 exists in 230 V (EU/UK/AU) and 120 V (US) versions. The thermoblock, pump, PCB and TCO are voltage-specific. AliExpress stock is almost entirely 230 V. Decide your mains voltage first and match **every** electrical part to it.

---

## 3. Component-by-Component Sourcing

Prices are 2026 ballparks; they fluctuate with seasonal sales and coupons. Part codes below are from the official De'Longhi **EC885.M exploded view** (`EC885 Exploded View .pdf` — the EC885 Dedica Arte shares its wet side with the EC685) and from the thesis part list (`860382060-Part-list-final.docx`, with live 4delonghi.co.uk links keyed to EC680).

### 3.1 Pump — ULKA EP5 / EX5 vibratory pump (~€12–25)

The heart of the machine and the easiest part to source — ULKA pumps are a de-facto industry standard used across De'Longhi, Gaggia, Saeco, Breville.

| Spec | Value |
|---|---|
| Model | ULKA EP5 (plastic outlet) or EX5 (brass outlet) |
| Power | 48 W, 230 V 50 Hz (120 V 60 Hz variant: EP5/EX5 120 V) |
| Max pressure | 15 bar |
| De'Longhi code | AS00002825 "PUMP (ULKA 230V 48W)" (exploded view #40) |
| Mounting | Rubber pump protector 5213211161 (#41) + spring 6113210761 (#42) |

- AliExpress: search `ULKA EP5 48W 230V` / `ULKA EX5 vibration pump` — e.g. [this EX5 listing](https://www.aliexpress.com/item/1005004294491879.html)
- eBay: [EP5 48W 230V](https://www.ebay.com/itm/173745525246), [EP5 15 bar](https://www.ebay.com/itm/387082132812)
- Official distributor: [ulkapumps.com](https://ulkapumps.com/en-us)
- The thesis used the Amazon UK ULKA EP5 (~£16) as a drop-in for the OEM pump.

**Chassis note:** the Dedica suspends the pump in a rubber sleeve + spring to damp vibration. The thesis's first rigid printed pump mount produced "unacceptable levels of vibration"; the second iteration replicated the OEM sleeve-and-spring suspension and fixed it. Copy the OEM mounting concept in the printed chassis.

### 3.2 Thermoblock ("generator") — 1300 W single-part (~€20–40)

Single-part aluminium thermoblock with embedded stainless pipe — low leak risk, low scale-up risk, 40 s heat-up.

| Spec | Value |
|---|---|
| De'Longhi code | 5513226671 "GENERATOR (230V 1300W + plastic connector)" (#60) — EC680/EC685 listings also appear as "generator/thermoblock EC680" |
| Sensor | NTC sensor 5217100200 (#55) + fixing bracket 6113211071 (#66) |
| Thermal cutoff | TCO 192 °C, code 511876 (#68) + bracket 6013211951 (#69) — **never omit this** |
| Gaskets | Generator gasket 5313228791 ×2 (#62), spacer 5332239300 (#61) |
| Connections | Right-angle generator connection 5313218931 (#70), connection 5332242400 (#67) |

- Search seeds: `EC685 thermoblock`, `Delonghi generator EC680 1300W`, `Dedica heating element`
- Dedicated Dedica spares pages: [espressocoffeeshop](https://spareparts.espressocoffeeshop.com/en/3901-de-longhi-ec685m-delonghi-dedica-parts), [FixPart EC685.M](https://fixpart.co.uk/coffee-machine-spare-parts/delonghi/ec685m-0132106138-dedica), [4delonghi.co.uk](https://www.4delonghi.co.uk/ec685m/catalogue.pl?path=316723&model_ref=13165954), [yourspares](https://www.yourspares.co.uk/parts/delonghi/coffee-machines/dedica-ec685m.aspx)
- US (120 V) sources: [eReplacementParts EC685M](https://www.ereplacementparts.com/models/coffee-maker/delonghi/id1362996/ec685m/), [Encompass](https://delonghi.encompass.com/model/DEIEC685M)

**Chassis note:** thermoblock skin runs well above 100 °C. Keep ≥10 mm air gap to any printed part, mount it on its OEM bracket geometry, and use ABS/ASA/PC (not PETG, never PLA) for anything within radiant range. The thesis mounted heater and SSRs on metal plates as heat sinks.

### 3.3 Group head — the part you must print (~€12 in gaskets + printing)

The OEM group head housing is integrated into the Dedica casing — the thesis cut it out of the donor case for prototype 1, then designed a 3D-printed ABS replacement for prototype 2 (a ~£12 open-source substitute for group heads that otherwise start at ~£95). **This is the flagship printed part of our chassis.** All the sealing internals are standard spares:

| Part | EC885 code (ref#) | ~Price |
|---|---|---|
| Brewing gasket | 46: 537177 (EC680 link in thesis docx) | €3 |
| Closure gasket | 47: 5313221481 | €3 |
| Brewing gasket support | 48: AS00005377 | €3 |
| Bottom/diffuser gasket | 49: AS00005075 | €3 |
| Diffuser (shower screen) | 52: 6013211191 | €3 |
| Connectors gasket | 54: 5313237781 | €3 |

- Thesis-verified EC680 purchase links for all of these are in `860382060-Part-list-final.docx`.
- Search seeds: `EC680 brewing gasket`, `Dedica diffuser`, `Delonghi 51mm shower screen`
- Print in **ABS/ASA** (thesis: PLA deformed; ABS survived because brew water never directly contacts the housing). Consider a printed housing clamping a machined/laser-cut aluminium or stainless face plate for the portafilter lugs if you want longevity beyond the thesis design.

### 3.4 Portafilter and filters (~€20–30)

| Part | EC885 code (ref#) |
|---|---|
| Filter holder assembly (51 mm) | 06: AS00002706 |
| Small 1-cup filter | 03: AS00003137 |
| Large 2-cup filter | 04: AS00003138 |
| ESE pods filter | 05: 5513281011 |

Aftermarket 51 mm bottomless portafilters for the Dedica are abundant on AliExpress (search `51mm bottomless portafilter Dedica`) and often nicer than OEM — a good open-source-friendly upgrade.

### 3.5 Valves — over-pressure, anti-drip, 3-way (~€10–20)

| Part | EC885 code (ref#) | Role |
|---|---|---|
| Anti-drip valve | 39: 7313260161 | stops dripping after shot |
| Valve (3-way) | 43: AS00004266 | releases puck pressure to drip tray |
| 3-way valve connector | 75: AS00005380 | |
| Spring | 42: 6113210761 | OPV spring (sets ~15 bar static) |
| Valve internals | thesis docx links: valve BARM30E, ring BAR16E, gasket | |

**Mod-friendly note:** the OPV spring is where people do the "9-bar mod" (community-documented for Dedica). An open chassis should make the OPV accessible without disassembly.

### 3.6 Flowmeter (~€10–15)

| Part | EC885 code (ref#) |
|---|---|
| Flowmeter | 45: 5213225251 |
| Flowmeter-pump tube | 37: AS00005774 |

Optional if you run OEM electronics (it's how the PCB doses single/double shots); essential for a smart open controller. Datasheet-driven (hall pulse output) — the thesis recommends wiring it to the microcontroller for volumetric dosing.

### 3.7 Water tank and tubing (~€20–35)

| Part | EC885 code (ref#) |
|---|---|
| Water tank | 32: 7313285109 (assembly 18: 5513200359) |
| Tank tube L270 | 31: 5313219841 |
| Tube L150 | 33: 5313236101 |
| Tube with 2 bushes L230 | 71: 7313285899 |
| Tube with 1 bush L135 | 72: 5513213661 |
| PTFE tube DI2-DE4 L100 | 73: 5532111900 |
| Tray gasket | 30: 5313236391 |
| O-rings D3.85 | 36: 5313217701 (×5+) |
| Springs (connector) | 35: 6132101300 (×4) |
| Clips AISI302 | 65: 6113213191 (×3) |

The OEM silicone/PTFE tube set with molded bushes is cheap — buy it rather than improvising fittings, and design the chassis around OEM tube lengths (or buy generic food-grade silicone tube 4×2 mm + PTFE 2×4 mm for custom routing). The tank is a good candidate to keep OEM (food-safe, has valve + level float geometry) or redesign later as a printed+bottle solution.

### 3.8 Steam system (optional, phase 2)

| Part | EC885 code (ref#) |
|---|---|
| Steam valve assembly | 17: AS00002707 |
| Steam hose assembly | 10: AS00002705 |
| Steam knob | 13: 7313285479 |
| Nozzle | 77: AS00002710 |

The thesis blocked the steam line with high-temp epoxy for prototype 1 and never re-added it. Recommend the same for v1: espresso first, steam later. If skipped, cap the 3-way valve's steam port properly (rated for 125 °C / 15 bar).

### 3.9 Electronics — two paths

**Path 1 — OEM PCB (fastest to working machine, ~€40–55):**

| Part | EC885 code (ref#) |
|---|---|
| Power PCB | 59: AS00002829 — AliExpress: [EC680/EC685 power board ~$40](https://www.aliexpress.com/item/4001101696035.html); eBay: [power PCB 230V EC680/685/695/785](https://www.ebay.com/itm/175759949100) |
| Control board (front buttons) | 15: 7313285189 |
| Microswitch | 16: 5113210421 |
| On/off button 28: 5913216331, unipolar switch 29: 5128109300, mains cord 53, wiring looms 56–58 | |

You keep OEM behavior (single/double dosing via flowmeter, 3 temperature levels) but the machine stays a black box.

**Path 2 — Open controller (the thesis route, ~€50–80):** microcontroller (the thesis used 2× Arduino Uno; today use one **ESP32**) + SSR for the 1300 W heater + relay/triac for the pump + MAX31855 thermocouple or NTC + the OEM flowmeter. Gets you PID temperature control, pre-infusion profiles, shot-by-flow, and eventually pressure display (see the [CaiJonas Dedica sensor mod](https://github.com/CaiJonas/DeLonghi-Dedica-EC885-EC685-modification) for a proven pressure+temp sensor BOM: 0–300 PSI G1/4 transducer, 104GT-2 NTC, OLED). The thesis wiring diagram and Arduino code are in its Appendix 2. Community PID projects (Gaggiuino-style) are the reference for doing this safely with proper mains isolation.

The thesis SSR/relay/thermocouple part links (RS, TME, Pimoroni) are preserved in `860382060-Part-list-final.docx`.

### 3.10 Chassis hardware (~€15)

- M3 heat-set inserts + M3 screws (the thesis tapped printed holes; inserts are better)
- Cup rack 07/12, drip tray 09: 5313249971 + float 08: 5313249981 — OEM tray is convenient, or design a printed tray + laser-cut grate
- Rubber feet 34/76 or printed TPU feet
- Optional: 3 mm acrylic panels (the thesis's second prototype used laser-cut black/clear acrylic with 16 printed corner brackets — a good look for an open machine: printed frame + acrylic skins)

---

## 4. Sourcing Tips

1. **Search by part code, then by description.** `5513226671` finds exact hits; `Dedica thermoblock` finds cheaper compatibles. AliExpress sellers often list under EC680 — the EC680/EC685/EC885 wet side is interchangeable for our purposes ([AliExpress EC685 search](https://www.aliexpress.com/w/wholesale-delonghi-ec685-accessories.html)).
2. **Cross-check codes against the exploded view.** `EC885 Exploded View .pdf` is the authoritative ref# ↔ code map (65 numbered positions). For EC685-specific codes use [FixPart's model pages](https://fixpart.co.uk/coffee-machine-spare-parts/delonghi/ec685m-0132106138-dedica) which index by PNC (e.g. 0132106138 = EC685.M).
3. **Buy wear parts ×2.** Gaskets, O-rings, springs, brew gasket — they're €2–3 each and you will tear one during assembly.
4. **Prices swing with sales** (11.11, Anniversary sale, coupons). The €30 part today is €18 next month.
5. **One seller ≠ one order.** Consolidate: most De'Longhi-spares AliExpress stores carry the pump, PCB, thermoblock and gasket kit simultaneously — one store, one shipment, one customs event.
6. **Keep the donor manuals.** `Magnifica Data Sheet and Service Manual.pdf` and `LA SPECIALISTA Data Sheet and Service Manual.pdf` show De'Longhi's service-level test procedures (resistance values, NTC curves) that transfer to the Dedica family.

---

## 5. From Parts to STEP Files (scan & CAD workflow)

Goal: a `step/` library where every purchased part has a dimensionally-trusted model, so the chassis is designed against reality.

**Per-part workflow:**
1. **Photograph** the part on a grid mat (top/bottom/sides + connector close-ups). Store in `SCANS/<part>/photos/`.
2. **Measure** critical interfaces with calipers: mounting hole patterns, boss diameters, tube spigots, connector pitch. Interfaces must be caliper-accurate — scans are for envelopes, calipers are for fits.
3. **Scan** organic/complex parts (thermoblock casting, pump body, tank): photogrammetry (60–100 photos, matte spray on shiny silicone/chrome) or a structured-light scanner. Export mesh (STL/PLY).
4. **Rebuild as parametric CAD**, don't ship raw meshes: import mesh as reference, model clean solids over it (Fusion/SolidWorks/FreeCAD). Simple parts (tubes, gaskets, brackets) get modeled from caliper dims alone.
5. **Export STEP (AP214)** to `step/` with the naming scheme `OD-Xnn_<name>.step` (e.g. `OD-H01_ulka_ep5_pump.step`; see [PART_NUMBERING.md](PART_NUMBERING.md)).
6. **Validate**: print a check-fixture (a ring or cradle) for each critical part and test-fit the real component before trusting the model in the chassis assembly.

We already have a FreeCAD batch pipeline (freecadcmd) for STEP→STL conversion from other projects — reuse it for print exports.

**Scan priority order** (what the chassis actually touches): pump + sleeve → thermoblock + brackets → group head gasket stack + portafilter lugs → water tank + valve seat → flowmeter → PCB outlines + button geometry → drip tray.

---

## 6. Chassis Design Rules (learned from the thesis + OEM teardown)

1. **Two-zone layout.** Wet zone (tank, pump, thermoblock, valves) physically separated from the electric zone (PCB/controller, SSR, mains) — the thesis literally used two boxes for prototype 1. In one chassis: a printed bulkhead + drainage path so a leak drips to the tray, not the PCB.
2. **Copy OEM anti-vibration.** Pump in rubber sleeve + spring, decoupled from panels; TPU feet. Rigid mounts = a machine that walks across the counter.
3. **Respect the thermal map.** Thermoblock and its 192 °C TCO stay clear of printed walls; SSR on an aluminium plate; ABS/ASA near heat, PETG elsewhere, PLA nowhere structural.
4. **Serviceability is the point.** The Dedica's worst trait (thesis: "very difficult to disassemble") is our biggest win: top + back panels removable with 4 screws each, OPV reachable, gaskets replaceable without unhousing the thermoblock.
5. **Design for the mug.** Group head height ≥ 95 mm above tray (thesis legs were sized for a standard mug); keep the 0.4 m³ envelope limit from the thesis spec.
6. **Pre-infusion & preheat are software.** The thesis proved the hardware is capable — temperature stability comparable to OEM (±2 °C) once control was open. Leave sensor bosses (M3/M4 on thermoblock, tee for a thermocouple between heater and group head) in the chassis design from day one.
7. **Safety spec carries over:** piping rated 125 °C / 15 bar, TCO always in the heater circuit, PAT-testable build, RCD during all testing.

---

## 7. Reference Documents

**Reference documents (not redistributed in this repo — copyrighted; obtain from the original sources):**
- `Open Source Espresso Machine for Makers.pdf` — Zack Moss, University of Sheffield 2019. The master reference: EC685.M reverse engineering, temperature experiments, two prototypes, wiring diagram + Arduino code + part list (Appendix 2).
- `860382060-Part-list-final.docx` — thesis parts list with live 4delonghi.co.uk EC680 purchase links (£295 total).
- `EC885 Exploded View .pdf` — official exploded diagram + full part-code table (positions 01–77).
- `LA SPECIALISTA / Magnifica Data Sheet and Service Manual.pdf` — De'Longhi service test values.
- `DESIGB.pdf` — VDI 2221 portafilter redesign paper (method reference for documenting our own redesigns).

**Online:**
- [Makerspet OOMWOO BOM guide](https://makerspet.com/blog/how-to-source-bom-for-oomwoo-open-source-vacuum-robot/) — the sourcing-guide format this document follows
- [CaiJonas Dedica EC685/EC885 mod repo](https://github.com/CaiJonas/DeLonghi-Dedica-EC885-EC685-modification) — reversible pressure/temperature monitoring, sensor BOM
- Spares indexes: [espressocoffeeshop](https://spareparts.espressocoffeeshop.com/en/3901-de-longhi-ec685m-delonghi-dedica-parts) · [FixPart](https://fixpart.co.uk/coffee-machine-spare-parts/delonghi/ec685m-0132106138-dedica) · [4delonghi](https://www.4delonghi.co.uk/ec685m/catalogue.pl?path=316723&model_ref=13165954) · [eReplacementParts (US)](https://www.ereplacementparts.com/models/coffee-maker/delonghi/id1362996/ec685m/) · [Encompass (US)](https://delonghi.encompass.com/model/DEIEC685M) · [ulkapumps.com](https://ulkapumps.com/en-us)

---

## 8. Workflow (Milestone 1)

**M1 definition:** donor machine torn down, every part catalogued against the BOM, STEP library validated with printed check-fixtures, printed group-head housing bench-tested under pressure.

Work is not assigned to people — it is tracked as **GitHub issues** that anyone can pick up. See [CONTRIBUTING.md](../CONTRIBUTING.md) for the scan → STL → STEP → chassis pipeline, naming rules and how to claim a task.

---

## 9. Next Steps

1. Pick mains voltage (230 V assumed below) and order a donor EC685 + wear-part kit (gaskets/O-rings/tubes ×2).
2. Tear down, photograph every stage, log each part against `BOM.md`.
3. Scan/measure per Section 5, build the STEP library.
4. Block out the two-zone chassis around the STEP assembly; print group-head housing first (highest risk part) and pressure-test it on the bench before designing the rest around it.
5. Decide Path 1 (OEM PCB) vs Path 2 (ESP32 + SSR) for v1 electronics.

*Find the master Bill of Materials in [BOM.md](BOM.md).*

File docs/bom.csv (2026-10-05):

part_no | parent | type | name | ref | oem_code | qty | cad | material_spec | source | price_eur | issue | status
OD-000 |  | ASM | Open Dedica espresso machine (top assembly) |  |  | 1 | DESIGN |  |  |  |  | todo
OD-H00 | OD-000 | ASM | Hydraulic core |  |  | 1 | DESIGN |  |  |  |  | todo
OD-H01 | OD-H00 | OEM | Pump ULKA EP5/EX5 48 W 230 V 15 bar | 40 | AS00002825 | 1 | SCAN |  | AliExpress `ULKA EP5 48W 230V` / eBay / ulkapumps.com | 12–25 | #1 | modeled
OD-H02 | OD-H00 | OEM | Pump protector (rubber sleeve) | 41 | 5213211161 | 1 | SCAN | rubber | AliExpress / FixPart | 4 | #1 | todo
OD-H03 | OD-H00 | OEM | Pump suspension spring | 42 | 6113210761 | 1 | CALIPER | steel | FixPart / 4delonghi | 3 | #1 | todo
OD-H10 | OD-H00 | ASM | Thermoblock sub-assembly |  |  | 1 | DESIGN |  |  |  | #2 | todo
OD-H11 | OD-H10 | OEM | Thermoblock (generator 230 V 1300 W + plastic connector) | 60 | 5513226671 | 1 | SCAN | aluminium casting | AliExpress `EC680 thermoblock` / espressocoffeeshop | 25–40 | #2 | modeled
OD-H12 | OD-H10 | OEM | Spacer | 61 | 5332239300 | 2 | CALIPER |  | 4delonghi | 3 |  | todo
OD-H13 | OD-H10 | OEM | Generator gasket | 62 | 5313228791 | 2 (+2 spare) | CALIPER | rubber | 4delonghi | 3 |  | todo
OD-H14 | OD-H10 | OEM | Connection | 67 | 5332242400 | 1 | CALIPER |  | 4delonghi | 3 |  | todo
OD-H15 | OD-H10 | OEM | Right-angle generator connection | 70 | 5313218931 | 1 | CALIPER |  | 4delonghi | 4 |  | todo
OD-H16 | OD-H10 | OEM | NTC sensor | 55 | 5217100200 | 1 | CALIPER |  | FixPart | 5 | #2 | todo
OD-H17 | OD-H10 | OEM | NTC fixing bracket | 66 | 6113211071 | 1 | SCAN | steel | FixPart | 3 | #2 | todo
OD-H18 | OD-H10 | OEM | TCO 192 °C thermal cutoff — **mandatory** | 68 | 511876 | 1 (+1 spare) | CALIPER |  | FixPart | 5 | #2 | todo
OD-H19 | OD-H10 | OEM | TCO fixing bracket | 69 | 6013211951 | 1 | SCAN | steel | FixPart | 3 | #2 | todo
OD-H21 | OD-H00 | OEM | Anti-drip valve | 39 | 7313260161 | 1 | SCAN |  | FixPart / 4delonghi | 5 | #41 | modeled
OD-H22 | OD-H00 | OEM | 3-way valve | 43 | AS00004266 | 1 | SCAN |  | 4delonghi `valve BARM30E` | 5 | #6 | modeled
OD-H23 | OD-H00 | OEM | 3-way valve connector | 75 | AS00005380 | 1 | CALIPER |  | 4delonghi | 3 | #6 | todo
OD-H24 | OD-H00 | OEM | Flowmeter | 45 | 5213225251 | 1 | SCAN |  | FixPart / 4delonghi | 10–15 | #7 | modeled
OD-H25 | OD-H00 | OEM | Flowmeter–pump tube | 37 | AS00005774 | 1 | ENVELOPE |  | FixPart | 4 |  | todo
OD-G00 | OD-000 | ASM | Group head |  |  | 1 | DESIGN |  |  |  | #3 | todo
OD-G01 | OD-G00 | PRINT | Group head housing (open-source replacement for the molded OEM housing; strength untested until OD-T01) |  |  | 1 | DESIGN | PLA for now (fit-check prints only — hot zone; service ASA) | printed (Creality K1C) | print | #3 | modeled
OD-G02 | OD-G00 | OEM | Brewing gasket | 46 | 537177 | 1 (+1 spare) | CALIPER | silicone | 4delonghi | 3 | #3 | todo
OD-G03 | OD-G00 | OEM | Closure gasket | 47 | 5313221481 | 1 (+1 spare) | CALIPER |  | FixPart | 3 | #3 | todo
OD-G04 | OD-G00 | OEM | Brewing gasket support | 48 | AS00005377 | 1 | SCAN |  | 4delonghi | 3 | #3 | modeled
OD-G05 | OD-G00 | OEM | Bottom (diffuser) gasket | 49 | AS00005075 | 1 (+1 spare) | CALIPER |  | 4delonghi | 3 | #3 | todo
OD-G06 | OD-G00 | OEM | Diffuser (shower screen) | 52 | 6013211191 | 1 | SCAN | stainless | 4delonghi | 3 | #3 | todo
OD-G07 | OD-G00 | OEM | Connectors gasket | 54 | 5313237781 | 1 | CALIPER |  | FixPart | 3 | #3 | todo
OD-G08 | OD-G00 | MFG | Group head face plate with portafilter lugs (optional upgrade) |  |  | 1 | DESIGN | aluminium / stainless (laser-cut or machined) | local shop | — |  | proposed
OD-G09 | OD-G00 | REF | OEM group head bayonet cup (molded into the case — reference geometry for OD-G01) |  |  | 0 | SCAN | molded plastic | donor | — | #38 | modeled
OD-G10 | OD-G00 | OEM | Portafilter 51 mm (filter holder assembly) | 06 | AS00002706 | 1 | SCAN |  | OEM / AliExpress `51mm bottomless portafilter Dedica` | 20–30 | #39 | modeled
OD-G11 | OD-G10 | OEM | Filter basket 1-cup | 03 | AS00003137 | 1 | CALIPER | stainless | OEM / aftermarket | 5 | #4 | todo
OD-G12 | OD-G10 | OEM | Filter basket 2-cup | 04 | AS00003138 | 1 | CALIPER | stainless | OEM / aftermarket | 5 | #4 | todo
OD-G13 | OD-G10 | OEM | ESE pods filter (optional) | 05 | 5513281011 | 1 | CALIPER |  | OEM | 5 |  | todo
OD-W00 | OD-000 | ASM | Water path |  |  | 1 | DESIGN |  |  |  |  | todo
OD-W01 | OD-W00 | OEM | Water tank assembly | 18 | 5513200359 | 1 | SCAN |  | FixPart / 4delonghi | 8–15 | #5 | todo
OD-W02 | OD-W01 | OEM | Water tank | 32 | 7313285109 | 1 | SCAN |  | 4delonghi / FixPart | (in OD-W01) | #5 | todo
OD-W03 | OD-W01 | OEM | Tray gasket (water tank seat — white seat with 2 barbed ports + black double gasket) | 30 | 5313236391 | 1 | SCAN |  | 4delonghi | 3 | #37 | modeled
OD-W11 | OD-W00 | OEM | Tube L270 (tank → flowmeter) | 31 | 5313219841 | 1 | ENVELOPE | silicone | 4delonghi | 4 |  | todo
OD-W12 | OD-W00 | OEM | Tube L150 | 33 | 5313236101 | 1 | ENVELOPE | silicone | FixPart | 4 |  | todo
OD-W13 | OD-W00 | OEM | Tube with 2 bushes L230 | 71 | 7313285899 | 1 | ENVELOPE |  | 4delonghi | 5 |  | todo
OD-W14 | OD-W00 | OEM | Tube with 1 bush L135 | 72 | 5513213661 | 1 | ENVELOPE |  | FixPart | 4 |  | todo
OD-W15 | OD-W00 | OEM | PTFE tube with 2 bushes DI2-DE4 L100 | 73 | 5532111900 | 1 | ENVELOPE | PTFE | FixPart | 4 |  | todo
OD-W21 | OD-W00 | OEM | Connector spring | 35 | 6132101300 | 4 | CALIPER | steel | 4delonghi | 8 (set) |  | todo
OD-W22 | OD-W00 | OEM | O-ring D3.85 T2 | 36 | 5313217701 | 5 (+5 spare) | CALIPER | rubber | 4delonghi | 8 (set) |  | todo
OD-W23 | OD-W00 | OEM | Clip (wire 1.2 AISI302) | 65 | 6113213191 | 3 | CALIPER | stainless | FixPart | 4 |  | todo
OD-E00 | OD-000 | ASM | Electronics (choose Path 1 OEM or Path 2 open controller) |  |  | 1 | DESIGN |  |  |  | #8 | todo
OD-E01 | OD-E00 | OEM | Power PCB 230 V — Path 1 | 59 | AS00002829 | 1 | SCAN |  | AliExpress 4001101696035 / eBay | 35–45 | #33 | modeled
OD-E02 | OD-E00 | OEM | Control board assembly (front buttons) — Path 1 | 15 | 7313285189 | 1 | SCAN |  | FixPart / eBay | 15–25 | #34 | modeled
OD-E03 | OD-E00 | OEM | Microswitch | 16 | 5113210421 | 1 | CALIPER |  | FixPart | 4 | #8 | todo
OD-E04 | OD-E00 | OEM | On/off push button | 28 | 5913216331 | 1 | CALIPER |  | FixPart | 3 |  | todo
OD-E05 | OD-E00 | OEM | Unipolar switch 16 A 250 V | 29 | 5128109300 | 1 | CALIPER |  | FixPart | 4 |  | todo
OD-E06 | OD-E00 | OEM | Power supply cord with plug (region-specific; AU code shown) | 53 | 5013276449 | 1 | ENVELOPE |  | FixPart / generic | 8 |  | todo
OD-E07 | OD-E00 | OEM | 6-pole wiring | 56 | 5013211961 | 1 | ENVELOPE |  | FixPart | 10 (set) |  | todo
OD-E08 | OD-E00 | OEM | Wiring with connectors | 57 | 5032509200 | 1 | ENVELOPE |  | FixPart | (set) |  | todo
OD-E09 | OD-E00 | OEM | Wiring | 58 | 5013276049 | 1 | ENVELOPE |  | FixPart | (set) |  | todo
OD-E51 | OD-E00 | ELEC | ESP32 dev board — Path 2 |  |  | 1 | VENDOR | 3.3 V WiFi | AliExpress | 5–10 |  | todo
OD-E52 | OD-E00 | ELEC | SSR for heater — Path 2 |  |  | 1 | VENDOR | ≥25 A zero-cross mains-rated | RS / TME (no no-name for mains) | 8–15 |  | todo
OD-E53 | OD-E00 | ELEC | Relay / SSR for pump — Path 2 |  |  | 1 | VENDOR | ≥2 A 230 V | RS / TME | 5–12 |  | todo
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

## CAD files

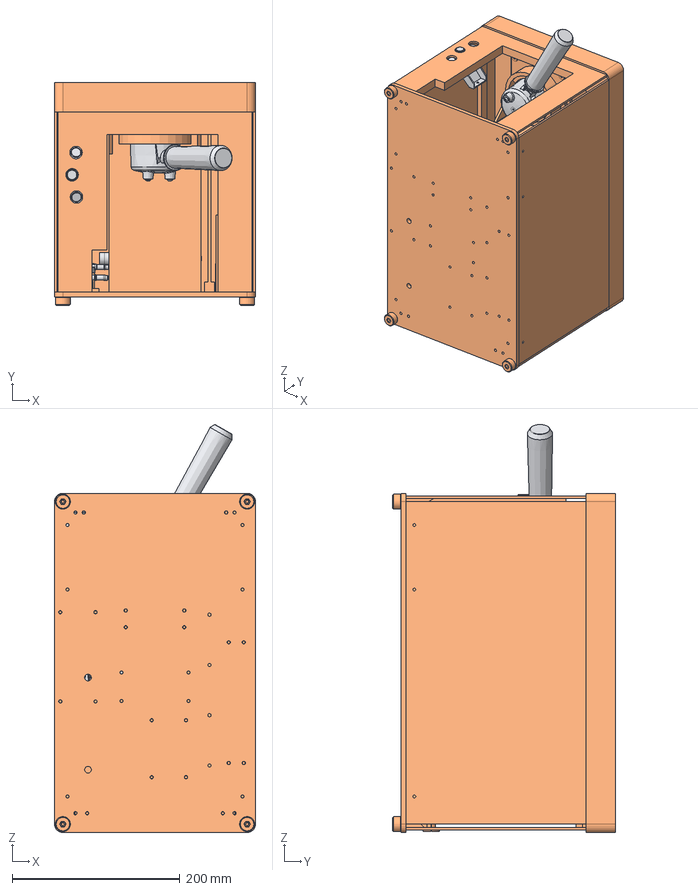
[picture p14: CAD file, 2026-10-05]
chassis/OD-000_open_dedica_assembly.step
240.0 x 266.0 x 487.1 mm
OD-C01
OD-C02
OD-C03
OD-C04
OD-C05
OD-C07
OD-C08
OD-C09
OD-C10
OD-C11
OD-C12
OD-C13
OD-C14-A
OD-C14-B
OD-C15-RF
OD-C15-LF
OD-C15-RR
OD-C15-LR
OD-C16-R1
OD-C16-R2
OD-C16-R3
OD-C16-L1
OD-C16-L2
OD-C16-L3
OD-G01
OD-G04
OD-G10
OD-H01
OD-H11
OD-H22
OD-H24
OD-E01
OD-E02

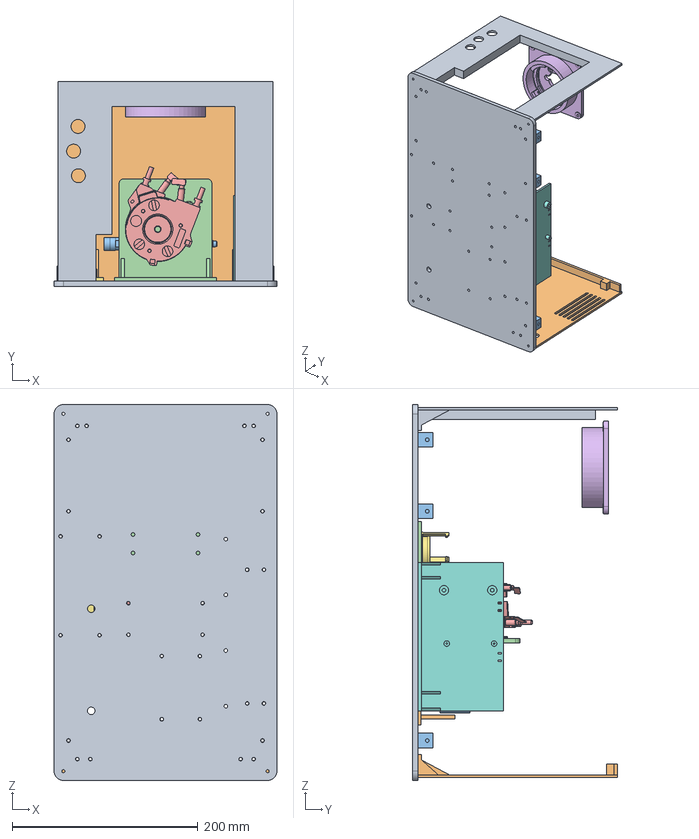
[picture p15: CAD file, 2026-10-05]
chassis/reports/OD-C01_base_frame/01_CAD/sweep_v03/drain_d_high/od_c01_assembly_C1_v03_drain_d_high.step
240.0 x 221.0 x 405.0 mm
od_c01_frame
od_c03_cradle
od_h01_pump
od_c04_mount
od_h11_thermoblock
od_g01_housing
od_c07_valve_mount
od_c08_tray
od_c09_front_panel
od_c11_back_panel
od_c16_r_z-262_bracket
od_c16_l_z-262_bracket
od_c16_r_z-15_bracket
od_c16_l_z-15_bracket
od_c16_r_z62_bracket
od_c16_l_z62_bracket
od_c05_foot_reference_A01

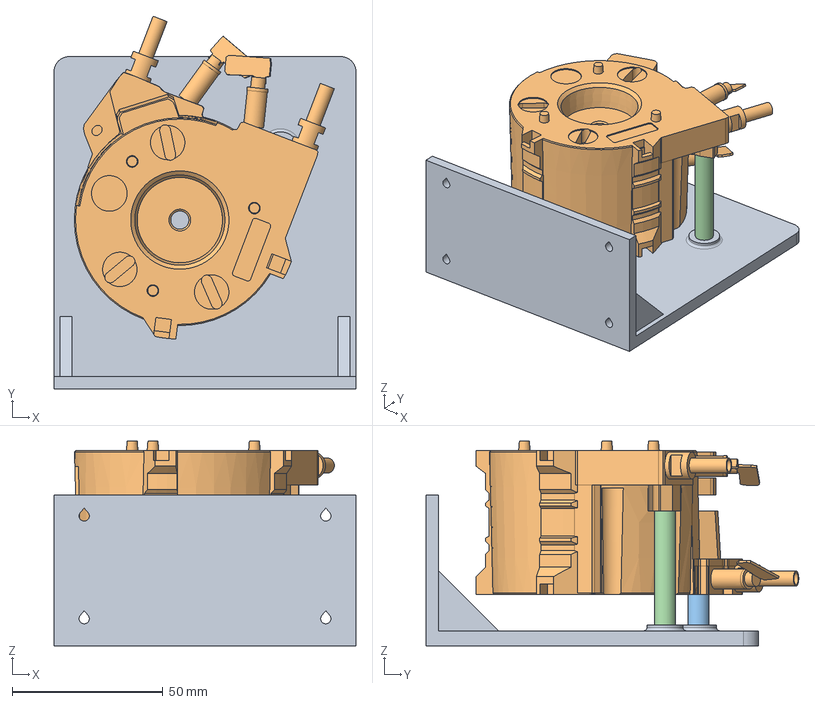
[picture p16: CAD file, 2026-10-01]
chassis/reports/OD-C04_thermoblock_mount/02_STEP_STL/od_c04_assembly_C1_v01.step
100.0 x 123.4 x 67.8 mm
od_c04_mount
OD-H11_thermoblock
spacer_S1_assumed_A05
spacer_S2_assumed_A05

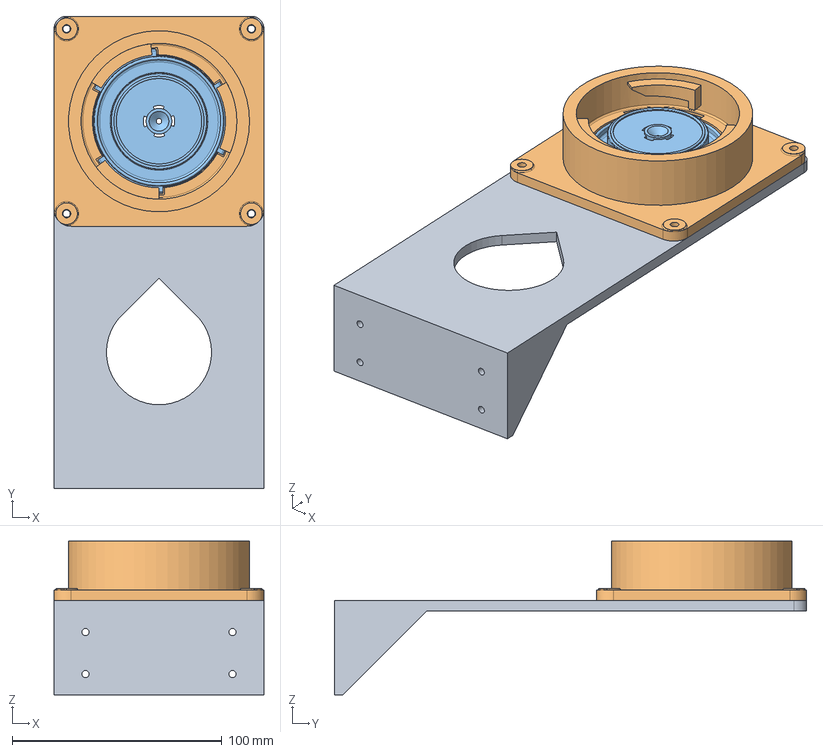
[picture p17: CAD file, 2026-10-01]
chassis/reports/OD-C05_group_head_carrier/02_STEP_STL/od_c05_assembly_C1_v01.step
100.0 x 225.0 x 73.2 mm
od_c05_carrier
od_g01_housing
od_g04_brewing_gasket_support

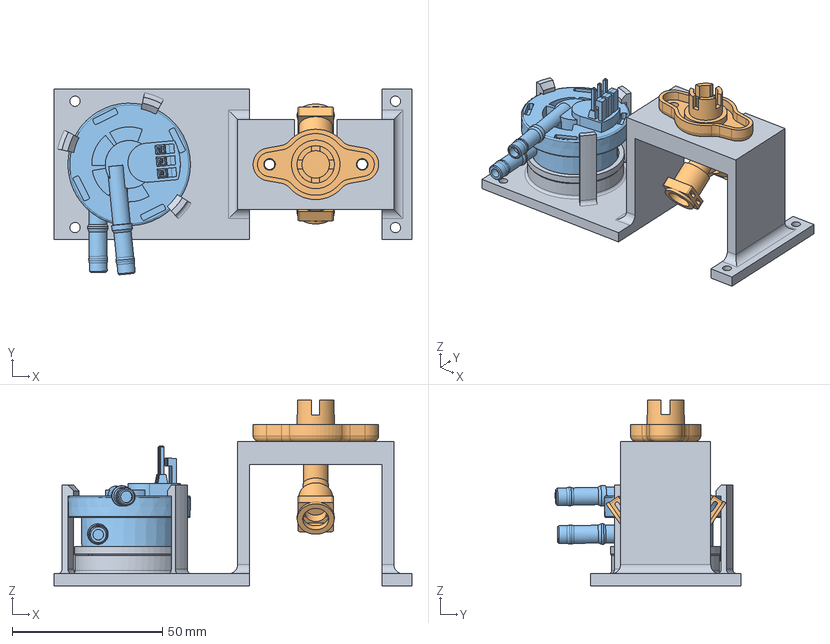
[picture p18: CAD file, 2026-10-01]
chassis/reports/OD-C07_valve_flowmeter_mount/02_STEP_STL/od_c07_assembly_C1_v01.step
119.0 x 61.7 x 61.7 mm
od_c07_mount
OD-H22
OD-H24

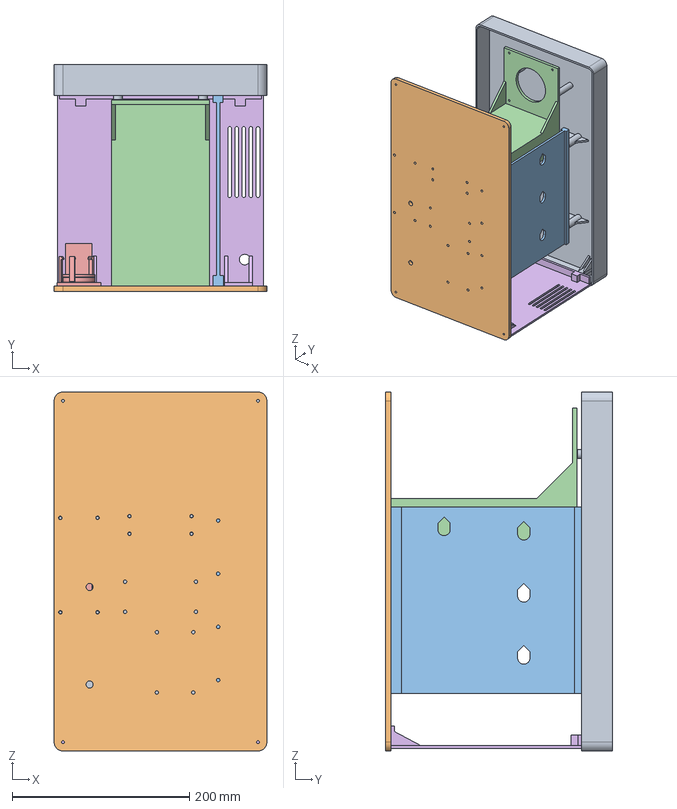
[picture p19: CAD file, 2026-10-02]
chassis/reports/OD-C10_top_panel/02_STEP_STL/od_c10_assembly_C1_v01.step
240.0 x 256.0 x 405.0 mm
od_c10_top
od_c01_frame
od_c02_bulkhead
od_c05_carrier
od_c07_valve_mount
od_c11_back

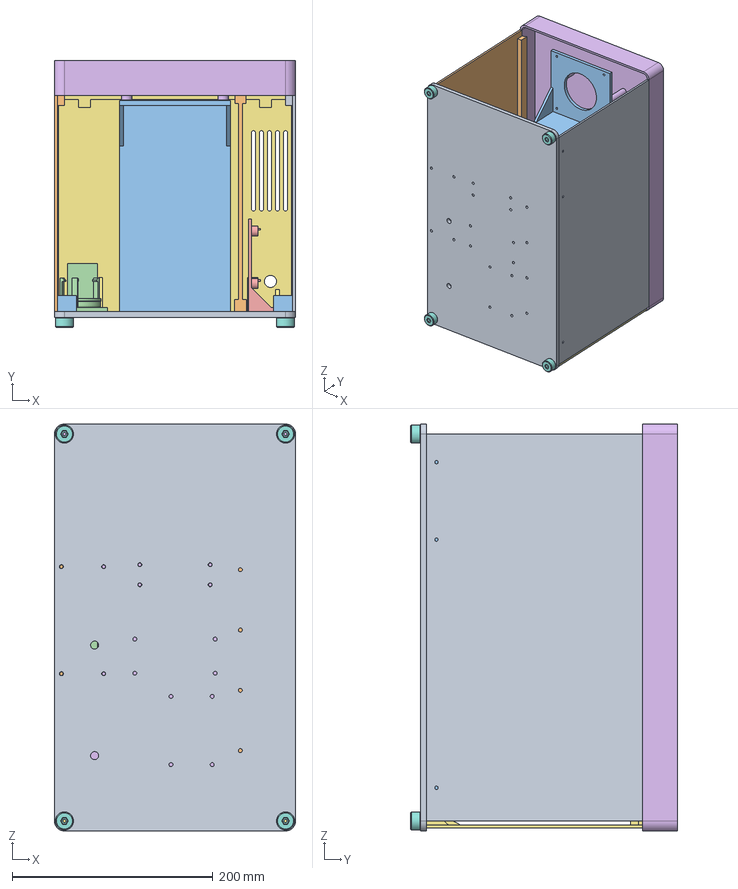
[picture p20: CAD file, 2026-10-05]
chassis/reports/OD-C12_C13_C16_side_panels/02_STEP_STL/od_side_assembly_C1_v01.step
240.0 x 266.0 x 405.0 mm
OD-C01
OD-C02
OD-C05
OD-C07
OD-C08
OD-C10
OD-C11
OD-C15-RF
OD-C15-LF
OD-C15-RR
OD-C15-LR
od_c13_right
od_c12_left
od_c16_bracket_R1
od_c16_bracket_L1
od_c16_bracket_R2
od_c16_bracket_L2
od_c16_bracket_R3
od_c16_bracket_L3

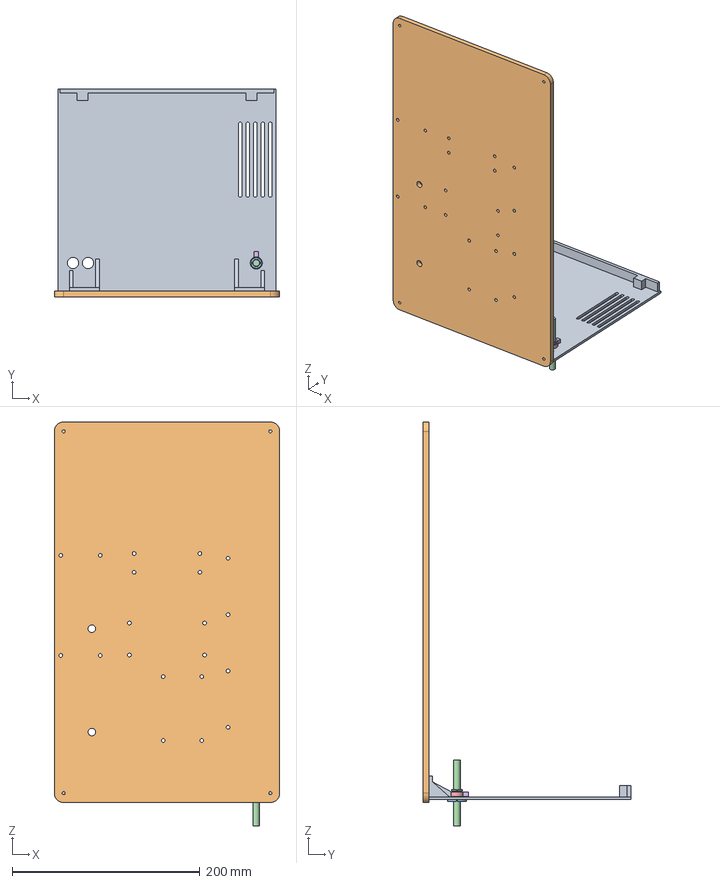
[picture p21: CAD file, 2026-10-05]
chassis/reports/OD-C14_cord_grommet/01_CAD/sweep_v01/bore_d_low/od_c14_assembly.step
240.0 x 221.0 x 430.0 mm
od_c11_back_panel
od_c01_base_frame
half_upper
half_lower
cord_envelope
tie_envelope
tie_head_box

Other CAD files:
chassis/reports/OD-C01_base_frame/01_CAD/sweep_v03/drain_d_low/od_c01_assembly_C1_v03_drain_d_low.step
chassis/reports/OD-C01_base_frame/01_CAD/sweep_v03/foot_d_high/od_c01_assembly_C1_v03_foot_d_high.step
chassis/reports/OD-C01_base_frame/01_CAD/sweep_v03/insert_d_high/od_c01_assembly_C1_v03_insert_d_high.step
chassis/reports/OD-C01_base_frame/01_CAD/sweep_v03/insert_d_low/od_c01_assembly_C1_v03_insert_d_low.step
chassis/reports/OD-C01_base_frame/01_CAD/sweep_v03/nominal/od_c01_assembly_C1_v03_nominal.step
chassis/reports/OD-C01_base_frame/01_CAD/sweep_v03/plate_t_high/od_c01_assembly_C1_v03_plate_t_high.step
chassis/reports/OD-C01_base_frame/02_STEP_STL/od_c01_assembly_C1_v03.step
chassis/reports/OD-C14_cord_grommet/01_CAD/sweep_v01/collar_d_high/od_c14_assembly.step
chassis/reports/OD-C14_cord_grommet/01_CAD/sweep_v01/groove_d_high/od_c14_assembly.step
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

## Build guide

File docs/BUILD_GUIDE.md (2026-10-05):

# Build guide: from the BOM to a running machine

This guide takes you from the bill of materials ([`bom.csv`](bom.csv), [BOM.md](BOM.md))
to an assembled Open Dedica. It collects what the part job records already say
(each printed part's spec in `chassis/reports/<part>/00_Spec/DESIGN_SPEC.md`, the
order of work and interfaces in [`chassis/README.md`](../chassis/README.md)) into one
sequence. Where the repository does not give a value, this guide says so instead of
filling it in.

Part numbers follow [PART_NUMBERING.md](PART_NUMBERING.md). Coordinates are mm in the
machine frame (X right, +Y up, +Z toward the front, plate top at y = 0) unless a
part's own frame is named.

## Contents

1. [Scope and status](#1-scope-and-status)
2. [Safety](#2-safety)
3. [What you need](#3-what-you-need)
4. [Printing](#4-printing)
5. [Heat-set inserts](#5-heat-set-inserts)
6. [Assembly sequence](#6-assembly-sequence)
7. [First power-up and tests](#7-first-power-up-and-tests)
8. [Open items](#8-open-items)

---

## 1. Scope and status

Read this before you print anything.

- **Every printed part is designed and reviewed in CAD only.** `OD-G01`, `OD-C01`…`OD-C05`,
  `OD-C07`…`OD-C16` and `OD-T01` are `modeled` in the BOM. Most were "approved on
  assumptions": every gate passes, but on values taken from 3D scans that nobody has
  confirmed with calipers yet. `OD-G01` was reviewed REVISE on its brew-load row
  alone (REQ-12), which only the `OD-T01` bench test can answer. The Usta accepted that
  as a documented deviation on 2026-10-02. `OD-C07` was reviewed REVISE as well, and
  the Usta accepted two seat gaps as deviations.
- **Nothing has been printed or fit-checked yet.** No part is `validated`. The first
  build is also the first fit check of every part.
- **Calipers beat scans on every interface.** Before you print a part, measure the
  OEM parts it touches and compare them with the open assumptions in its spec §6 (see
  [§8](#8-open-items)). If a measurement disagrees, stop and report it on the part's
  issue. Do not file the print to fit.
- **The base plate `OD-C01` is revision B** (spec 1.3, build v03, RV02 approved on
  assumptions): 38 Ø4.0 holes through the 6 mm plate (the 20 of revision A plus 18 for
  `OD-C08`, `OD-C11`, `OD-C16` and `OD-C09`), 4 Ø3.4 feet holes and 2 Ø8 drain holes.
- The steam system (`OD-S00`) is phase 2 and is not in this build. The water tank dock
  `OD-C06` is deferred, so the tank stands on the table behind the machine.
- The top assembly `chassis/OD-000_open_dedica_assembly.step` places every part below
  (33 solids, no interference; `chassis/src/OD-000_assembly/clash_report.md`). Use it to
  check the steps.

## 2. Safety

This is a mains-powered pressure appliance. Read this section in full.

- **Mains electrics.** The machine runs on mains voltage (230 V for the parts in this
  BOM; the EC685 also exists in 120 V, and every electrical part must match your mains,
  [SOURCING_GUIDE §2](SOURCING_GUIDE.md)). **All mains wiring, and the thermoblock's
  connections, must be done or checked by someone competent in mains electrics.**
- **Earth.** Bond earth to every metal part. The printed chassis does not conduct, so
  check earth continuity from the plug's earth pin to each metal part.
- **Unplug the machine whenever it is open.** Do not rely on the switch.
- **Keep the thermal cutoff.** The 192 °C TCO `OD-H18` stays in the heater circuit at all
  times ([SOURCING_GUIDE §6](SOURCING_GUIDE.md) rule 7; [CONTRIBUTING](../CONTRIBUTING.md)).
- **Test behind an RCD/GFCI**, and keep the build PAT-testable (README; SOURCING_GUIDE §6).
- **Pressure and heat.** Brew pressure is about 15 bar (the ULKA pump's rated
  maximum and the OEM over-pressure valve setting). The README and the `OD-G01` spec
  give water temperatures of up to about 125 °C on the hot side. The housing carries
  about 3.06 kN at 15 bar on a Ø51 basket (`OD-G01` A-21).
- **Keep wet and electric apart.** The bulkhead `OD-C02` separates the wet zone (x < 59)
  from the electric zone (x ≥ 70). Keep the drain holes in `OD-C01` clear.

**All printed parts are PLA for now.** This was the Usta's decision on 2026-10-02.
`bom.csv` lists each part's service material next to it. PLA softens at about
55–60 °C (the repository says "near 60 °C"), so:

- **PLA prints of `OD-G01`, `OD-C04` and `OD-C05` are dry fit checks only.** Never run
  hot water or pressure through them, and never power the thermoblock with them fitted.
- **The group head housing `OD-G01` must be printed in ASA and must pass the `OD-T01`
  bench pressure test behind a shield before any hot use** (section 7.1). Its strength
  has not been calculated or tested.
- `OD-C04` (service ASA/PC) and `OD-C05` (service ASA) must be reprinted in their
  service material before the thermoblock is ever powered.
- `OD-C02` sits 13 mm from the thermoblock casting (≈ 130 °C, its spec §3). Its service
  material is ASA, and SOURCING_GUIDE §3.2 asks for ABS/ASA/PC for anything within
  radiant range of the thermoblock. Print it in ASA before the first hot run as well.
- The front panel `OD-C09` (≈ 9 mm from the warm group head), the lid `OD-C10` and the
  side panels `OD-C12`/`OD-C13` each have an open assumption that asks for a
  temperature reading in the running machine (C09 A-11, C10 A-10, C12/C13 A-08). If a
  reading comes near PLA's softening point, reprint the part in its service material.
  The geometry stays the same.
- The `OD-T01` rig is PLA by design. It is used with cold water only, so PLA's heat
  limit does not apply to it.

## 3. What you need

### 3.1 OEM parts: sourcing

Follow [SOURCING_GUIDE.md](SOURCING_GUIDE.md). The recommended route is **Strategy A:
a donor machine** (a used or broken Dedica EC680 / EC685 / EC885), stripped for every
functional part, plus new wear parts. Buy the wear parts twice, because you will tear
one during assembly: gaskets `OD-G02`, `OD-G03`, `OD-G05`, generator gaskets `OD-H13`,
O-rings `OD-W22` and the brew gasket (SOURCING_GUIDE §4 tip 3).

Before and during teardown, **photograph every stage, especially the wiring, the tube
runs and the group head stack**. The repository has no wiring diagram yet (see 6.10),
and the donor is the reference.

For v1 (electronics path 1, no steam) you need the BOM's OEM rows for the hydraulic
core `OD-H01`…`OD-H25`, the group head and portafilter `OD-G02`…`OD-G07`,
`OD-G10`…`OD-G12`, the water path `OD-W01`…`OD-W23`, the electronics `OD-E01`…`OD-E09`
and the drip tray and cup rest `OD-C21`…`OD-C24`. The quantities and OEM codes are in
[BOM.md](BOM.md).

### 3.2 Hardware (`OD-F` rows)

Quantities from `bom.csv`. The "used for" column comes from the BOM text and
`chassis/README.md`.

| Part | Item | BOM qty | Used for |
|---|---|---|---|
| `OD-F01` | M3 heat-set insert, Ø4.0 bore × 6 | ~70 | every printed screw joint (count in §5) |
| `OD-F02` | M3×8 screw, ISO 7380 / DIN 912 A2 | ~65 | mounts, tray, panels, brackets, lid, housing to carrier |
| `OD-F03` | Acrylic sheet 3 mm | per design | **not used**: the side panels are printed (status `deferred`) |
| `OD-F04` | Food-safe silicone tube 4×2 mm | 1 m | routing reserve |
| `OD-F05` | High-temp epoxy (125 °C / 15 bar) | 1 | blanking port B of `OD-H23` (the steam port) in v1 |
| `OD-F06` | 6.3 mm insulated spade terminals + 105 °C wire | 1 set | your own looms, where an OEM loom does not reach |
| `OD-F07` | Metal spacer Ø7 × 10.10 (Ø4 bore), cut +0.10/−0 | 1 | `OD-C04` standoff S1 to the thermoblock |
| `OD-F08` | Metal spacer Ø7 × 37.70 (Ø4 bore), cut +0.10/−0 | 1 | `OD-C04` standoff S2 to the thermoblock's mid lug |
| `OD-F09` | Cable tie 4.8 mm | 3 | 2 × `OD-C03` pump strap, 1 × `OD-C14` grommet |
| `OD-F15` | Cable tie 2.5 mm | 2 | `OD-C08` loom slots (2.0 × 4.0) |
| `OD-F16` | Self-tapping screw Ø3.5 | 2 | `OD-C04` into the thermoblock through the spacers: S1 ≈ 22, S2 ≈ 50 long (A-04; measure the donor's screws) |
| `OD-F10` | M3×12 screw | 8 | 4 × `OD-C02` from below the plate, 4 × `OD-C15` feet from the plate top |
| `OD-F11` | M3×6 screw | 2 | `OD-E01` board holes H1/H2 into the `OD-C08` standoffs |
| `OD-F12` | M3 hex nut, ISO 4032 A2 | 4 | captive in the `OD-C15` feet |
| `OD-F13` | M3×18 screw, ISO 4762 / DIN 912 | 2 | `OD-E02` button board into the `OD-C09` bosses |
| `OD-F14` | M3×10 screw, ISO 7380 | 4 | `OD-T01` rig into the `OD-G01` inserts (bench only) |

Notes:

- **The OD-C04 thermoblock screws (`OD-F16`)** are an assumption (`OD-C04` A-04):
  Ø3.5 self-tapping screws into the thermoblock's own pilot holes, about 22 long for S1
  and about 50 long for S2. Measure the OEM screws before you choose.
- **The OEM `OD-G04` screws** (two self-tapping screws, Ø3.5 assumed, `OD-G01` A-26)
  come from the donor.
- **`OD-C08` tie slots:** the slots are 2.0 × 4.0 and the spec calls for a 2.5 mm tie.
  Use the 2.5 mm ties `OD-F15` there; a 4.8 mm `OD-F09` will not pass them.
- **`OD-C15` feet:** if you use a nylon-insert nut (ISO 10511), you need an M3×16
  instead of the M3×12. A drop of medium threadlocker on the M3×12 is the spec's
  suggestion against creep (`OD-C15` A-07).

Tally of the screws this guide uses: 50 × `OD-F02`, 8 × `OD-F10`, 2 × `OD-F11`,
2 × `OD-F13` and 4 × `OD-F14`. The BOM quantities include spares.

### 3.3 Tools

- **Printers.** The specs name two: a **Creality K1C** (enclosed; needed for ASA and PC)
  and an **Anycubic Kobra Max 3** (large panels). Neither printer's build volume is in
  the workshop's machine files. The specs assume 220 × 220 × 250 for the K1C and
  420 × 420 × 500 for the Kobra Max 3. Check that your printer matches before you print
  the large parts.
- **Heat-set insert tool** (soldering iron with an M3 insert tip). The insert
  temperature is not given in the repository: use the insert maker's figure.
- **Calipers** (0.05 mm resolution, as in CONTRIBUTING's scan rules).
- **Hex keys and drivers** for the M3 heads you stock. The `OD-T01` procedure uses a
  2 mm key for its ISO 7380 M3 × 10.
- **A long M3 driver with ≥ 210 mm reach** for the four `OD-C05` foot screws. Their
  heads sit 203–204.4 mm below the carrier's top face (`OD-C05` RV02 F5).
- Side cutters for the cable ties; a multimeter for the earth continuity checks.
- For the bench test: the `OD-T01` parts list in
  [`chassis/OD-T01_TEST_PROCEDURE.md`](../chassis/OD-T01_TEST_PROCEDURE.md) (hand
  hydrostatic test pump, 0–25 bar gauge, bleed valve and tee, tube rated ≥ 25 bar,
  stainless 51 mm blind basket, polycarbonate shield, safety glasses).

## 4. Printing

The STL/3MF files are in `chassis/`. For each part, the table gives the printer,
orientation and supports from its spec §3/§4 and `chassis/src/<part>/README.md`.
Layer height, wall count, nozzle and bed temperatures are **not given** in the
repository, except the 100 % infill for `OD-T01`. Use your slicer's defaults for the
material, and use generous walls around the insert holes.

| Part | Name | Qty | Printer | Orientation | Supports | Notes | Service material (BOM) |
|---|---|---|---|---|---|---|---|
| `OD-G01` | Group head housing | 1 (+1 ASA) | K1C | mouth up, rear face on the bed | under the three lugs and three stop blocks only | PLA = dry fit only. Print the ASA housing for `OD-T01` and the machine. Lug roots are sharp, no fillet (RV01 F4) | ASA |
| `OD-C01` | Base plate | 1 | Kobra Max 3 | flat, bottom face on the bed | none | brim against warp (A-14); 240 × 405 × 6. Revision B: 38 Ø4.0 holes | PETG or ASA |
| `OD-C02` | Wet/electric bulkhead | 1 | K1C | standing on its rear end (z −240), 215 × 14 footprint, 210 tall | none | the four Ø14 windows have 45° gable roofs | ASA |
| `OD-C03` | Pump cradle | 1 | Kobra Max 3 (spec) | foot on the bed, saddles up | none | tie slots have 45° roofs | PETG |
| `OD-C04` | Thermoblock mount | 1 | K1C | plate back face on the bed, foot standing up | none | PLA = dry fit only | ASA / PC |
| `OD-C05` | Group head carrier | 1 | K1C | plate on the bed, foot up; 110 × 152 on the bed, 210 tall | none | the eight counterbore floors bridge (named exception). PLA = dry fit only | ASA |
| `OD-C07` | Valve and flowmeter mount | 1 | Kobra Max 3 (also fits the K1C) | bottom face on the bed | under the deck and the three hook catches only | | PETG |
| `OD-C08` | Electronics bay tray | 1 | K1C | lying on the wall's outer face (x 73); 92 × 160 on the bed, 39 tall | none | | PETG |
| `OD-C09` | Front panel | 1 | Kobra Max 3 | lying on the front face; 232 × 215 on the bed, 25 tall | none | brim if the plate lifts; about 119 g | ASA |
| `OD-C10` | Top panel (lid) | 1 | Kobra Max 3 | upside down, top face on the bed; 240 × 405, 39.5 tall | none | brim against warp (A-08) | PETG |
| `OD-C11` | Back panel | 1 | Kobra Max 3 | lying on the outer face; 232 × 215 on the bed, 25 tall | none | | PETG |
| `OD-C12` | Left side panel | 1 | Kobra Max 3 | lying on the outer face; 385 × 219 on the bed, 10 tall | none | brim against warp (A-11) | ASA / PETG |
| `OD-C13` | Right side panel | 1 | Kobra Max 3 | as `OD-C12` | none | brim against warp | ASA / PETG |
| `OD-C14` | Cord grommet half | 2 | K1C | standing on the flange's outer face | none | two identical halves | TPU |
| `OD-C15` | Foot | 4 | K1C (direct drive for TPU) | top face (the face against the plate) on the bed | none | the nut enters from the counter side | TPU 95A |
| `OD-C16` | Side panel corner bracket | 6 | K1C | on its underside | none | three per side; the left ones are the same part turned 180° | ASA / PETG |
| `OD-T01` | Pressure-test rig | 1 | Kobra Max 3 | lying on its rear face (z −60); 240 × 160 on the bed, 120 tall | none | **100 % infill** (or at least solid round the four counterbores); brim if it lifts; about 1.4 kg of PLA | PLA (cold water only) |

The `OD-C15` spec designs the foot in TPU 95A, and its nut pocket (5.60 across flats
for a 5.50 nut) grips by the TPU's give. A PLA foot printed "for now" is a hard puck,
and the nut fit is untested in PLA.

## 5. Heat-set inserts

All inserts are `OD-F01`: M3, 5.7 long, Ø4.6 outside, pressed into Ø4.0 holes (`OD-C01`
A-11; the stocked insert's datasheet is not confirmed yet). Set each one square and
flush with the face it is driven from.

**Rule: before you set any inserts, check each insert pattern with calipers against
the part that bolts onto it** (hole spacing and position from an edge), and fit the
mating part dry. A misplaced insert is hard to recover from.

| Where | Count | Driven from | Takes |
|---|---|---|---|
| `OD-C01` plate: `OD-C05` carrier | 4 | plate top | (±35, z −40), (±35, z −60) |
| `OD-C01`: `OD-C04` thermoblock mount | 4 | plate top | (±40, z −148), (±40, z −114) |
| `OD-C01`: `OD-C03` pump cradle | 4 | plate top | (−4 / 37, z −239 / −171) |
| `OD-C01`: `OD-C07` valve and flowmeter mount | 4 | plate top | (−113 / −71, z −42 / −148.5) |
| `OD-C01`: `OD-C08` tray (rev B) | 4 | plate top | (88 / 106, z −222 / −78) |
| `OD-C01`: `OD-C11` back panel (rev B) | 4 | plate top | (±81 / ±95, z −282) |
| `OD-C01`: `OD-C16` brackets (rev B) | 6 | plate top | (±104.5, z −262 / −15 / +62) |
| `OD-C01`: `OD-C09` front panel (rev B) | 4 | plate top | (±85 / ±95, z +77) |
| `OD-C02` base rail | 4 | rail underside (y 0) | M3×12 from below the plate |
| `OD-C02` top rail | 2 | rail top (y 215) | lid screws at (65, z −60 / −210) |
| `OD-C07` deck | 2 | deck underside | `OD-H22` ear screws |
| `OD-C08` standoffs H1, H2 | 2 | standoff tips | `OD-E01` board |
| `OD-C09` bosses | 2 | boss end faces | `OD-E02` button board |
| `OD-C11` ledge bosses | 2 | ledge top (y 215) | lid rear screws at (±90, z −293) |
| `OD-C16` brackets | 6 (1 each) | bracket outer face | side panel screws |
| `OD-G01` rear face | 4 | rear face | `OD-C05` (machine) or `OD-T01` (bench), at (±44, ±44) |
| **Total** | **58** | | 34 in the plate, 24 in other parts |

Notes:

- **Leave the four plate holes on the bulkhead line (x 65, z −45 / −105 / −165 / −225)
  empty.** They are clearance holes for the `OD-C02` M3×12 screws from below, and the
  inserts for that joint sit in the bulkhead's rail. So the plate's 38 holes take 34
  inserts.
- `OD-C07`'s two deck inserts go in from below. Set them before the mount is screwed to
  the plate.
- `OD-G01`'s insert holes have no depth margin and open on the flange front (RV01 F6).
  Press the inserts flush and no deeper. Each housing you print (the PLA fit check, the
  ASA test and service housing) needs its own four.
- `OD-C02`: an M3×12 ends exactly on the base-rail bore floor (RV01 F2). Before the
  final assembly, check that each screw clamps rather than bottoms out. A shorter screw
  or a deeper bore is the Usta's call.
- `OD-C08`: an M3×8 through the board bottoms 0.44 past the bore floor, so use M3×6
  (`OD-F11`), or an M3×8 with a washer ≥ 0.5 (RV01 F3).

## 6. Assembly sequence

The machine is built up from the plate. The order below follows the constraints the
part jobs recorded (chassis/README "Keep-outs" and the specs' assembly notes). Where
the order is this guide's inference rather than a recorded constraint, the step says
so. Dry-fit every part with its OEM neighbour before you drive screws.

Placement summary (plate frame, top view):

| Zone | x | z | What |
|---|---|---|---|
| Front, centre | ±75 | −15 … +85 | drip tray zone (keep the plate top clear) |
| Front-centre, behind the tray | ±55 | −70 … −26 | `OD-C05` foot (group head carrier) |
| Centre | ±50 | −157 … −107 | `OD-C04` foot (thermoblock mount) |
| Rear | −10 … 42 | −245 … −165 | `OD-C03` foot (pump across the back) |
| Left | −117 … −67 | −154 … −35 | `OD-C07` (valve and flowmeter) |
| Bulkhead line | 59 … 71 | −240 … −30 | `OD-C02` |
| Right (electric zone) | 73 … 112 | −230 … −70 | `OD-C08` with the board |
| Rear strip | ±70 | −305 … −250 | reserved tank zone (the tank now stands on the table) |

### 6.1 Plate: inserts and checks

Parts: `OD-C01`, 34 × `OD-F01`.

1. Check the plate: 240 × 405 × 6, 38 Ø4.0 holes, 4 Ø3.4 feet holes at (±110, +90) and
   (±110, −295), 2 Ø8 drain holes at (−80, −120) and (−80, −230).
2. Lay it on a flat surface and check for warp (record it: `OD-C01` REQ-09, §7.4).
3. Set the 34 inserts from the top face (§5). Leave the four x 65 holes empty.

### 6.2 Bulkhead `OD-C02`

Parts: `OD-C02` with its 6 inserts set, 4 × `OD-F10` M3×12.

The bulkhead is screwed from **below**: turn the plate over (`OD-C02` A-03), so this is
easiest while the plate is still bare (a recorded constraint).

1. Stand the bulkhead on the plate with its base rail over the four x 65 holes, wet face
   (x 59) toward the left. The rail's bores line up with the plate holes.
2. Turn the plate and bulkhead over together. Drive the four M3×12 up through the plate
   into the rail inserts. The heads sit under the plate, where the feet lift it clear of
   the counter.

### 6.3 Feet `OD-C15`

Parts: 4 × `OD-C15`, 4 × `OD-F10` M3×12, 4 × `OD-F12` nut.

1. Push a nut into each foot's hex pocket from the counter side.
2. Hold each foot under its Ø3.4 hole and drive the M3×12 from the plate top. The screw
   pulls the nut up onto its seat. Snug, not crushed. Add threadlocker if you like
   (A-07).
3. **Keep-out:** a Ø8 × 2.0 cylinder above each foot hole on the plate top stays free
   for the screw head (`OD-C15` A-09). Nothing else may sit there.

### 6.4 Pump cradle `OD-C03` and pump `OD-H01`

Parts: `OD-C03`, `OD-H01` in its rubber sleeve `OD-H02`, 4 × `OD-F02`, 2 × `OD-F09`.

1. Screw the cradle to the plate: 4 × M3×8 from above through the foot into the inserts
   at (−4 / 37, z −239 / −171).
2. Lay the pump in its sleeve on the two saddles. The pump axis runs along X at y 40,
   terminal block up and outlet toward −X (the valve side) (`OD-C03` A-08). The OEM
   spring `OD-H03` is not used by this cradle (A-05).
3. Pass two 4.8 mm cable ties through the post slots and over the sleeve, then pull them
   tight enough to hold the pump without crushing the sleeve.

The sleeve's outside diameter (53.3) is an assumption that no input gave. If the
saddles do not fit your sleeve, measure it and report it rather than forcing it
(`OD-C03` A-03).

### 6.5 Thermoblock mount `OD-C04` and thermoblock `OD-H11`

Parts: `OD-C04` (ASA/PC for any powered use), `OD-H11` with its NTC `OD-H16` on bracket
`OD-H17` and TCO `OD-H18` on bracket `OD-H19`, spacers `OD-F07` (10.10) and `OD-F08`
(37.70), 2 × `OD-F16` thermoblock screws (see §3), 4 × `OD-F02`.

The repository does not record an order for this joint. This order is inferred from the
geometry: the rear foot screws sit under the thermoblock, and the thermoblock screws are
driven from behind the mount's rear plate, toward where the pump now sits.

1. Cut the spacers to length (+0.10/−0) and deburr them.
2. Screw the mount to the plate first: 4 × M3×8 from above into the inserts at (±40,
   z −148 / −114). The rear plate faces the pump and the standoffs face the group head.
3. Offer the thermoblock: axis horizontal along Z, pipes and terminals up (`OD-C04`
   A-07). Put S1's 10.10 spacer between standoff S1 and the base face, and S2's 37.70
   spacer between standoff S2 and the mid-lug underside. Drive the two screws from the
   rear face of the mount through the standoffs and spacers into the thermoblock's blind
   holes.
4. Check the air gap: no printed surface may come within 10 mm of the casting (`OD-C04`
   REQ-01; the standoff tips sit 10.10 from it). The lowest point of the casting sits
   16.5 above the plate.

If the pump blocks a driver behind the mount, fit the thermoblock before 6.4.

### 6.6 Group head: housing `OD-G01` on carrier `OD-C05`

Parts: `OD-G01` (ASA for any wet use; PLA only for a dry fit), its 4 inserts, OEM stack
`OD-G04` with its two OEM screws, gaskets `OD-G02`, `OD-G03`, `OD-G05`, diffuser `OD-G06`;
`OD-C05`; 8 × `OD-F02`.

**Fit only a housing that has passed the `OD-T01` test (§7.1) into a machine that will
see water.**

1. Assemble the OEM group head stack into the housing as it came out of the donor
   cup: the gasket support `OD-G04` on the floor with its two screws through the pair-B
   holes from the rear, plus the gaskets and the diffuser. The repository does not
   document the stack order, so follow your teardown photos.
2. Test the bayonet dry: insert the portafilter `OD-G10` turned about −50°, lift it and
   lock it. Note the handle angle at lock. It should lock turned about 28° toward the
   right (`OD-C09` A-05).
3. On the bench, put the housing's rear face against the underside of the carrier's plate
   (the designed contact). Drive 4 × M3×8 from above through the Ø6.5 counterbores into
   the housing's inserts at (±44, ±44).
4. Stand the carrier on the plate with its foot over the inserts at (±35, z −40 / −60).
   The group head axis is vertical with the mouth down, over the tray zone. Drive the four
   foot screws (M3×8) through the **hatch** with the ≥ 210 mm driver.
5. Check: the housing's rear face is about 205 above the plate, and the mouth face about
   176.8 (`OD-C05` A-03; this layout still awaits the Usta's confirmation).

The column's foot is an undrained trough with the screw heads at its lowest point
(`OD-C05` RV02 F2). Keep water from falling through the hatch, and check it after the
leak tests.

### 6.7 Valve and flowmeter mount `OD-C07`

Parts: `OD-C07` with its 2 deck inserts set (from below, before this step), flowmeter
`OD-H24`, 3-way valve `OD-H22`, 6 × `OD-F02`.

1. Screw the mount to the plate: 4 × M3×8 from above through its footprint holes into
   the inserts at (−113 / −71, z −42 / −148.5). The flowmeter end faces the front and the
   valve end faces the pump.
2. Press the flowmeter down onto its pedestal until the three hooks catch the flange.
   The axis is vertical, the pipes face the tank side (in the mount's frame, −Y) and the
   connector faces the valve (`OD-C07` A-21).
3. Slide the valve into the deck slot at its seated height (along the mount's −Y, i.e.
   from the left side of the machine), ports under the deck and drive tube up. Drive
   2 × M3×8 down through the ears into the deck inserts.
4. **Do this before the left side panel `OD-C12` goes on.** With its screws loose, the
   valve slides out along the mount's +Y, toward the left panel (A-22).

The OPV sits inside the valve's drive tube and is reached from above with the lid off
(`OD-C07` A-10).

### 6.8 Electronics tray `OD-C08` and board `OD-E01` (path 1)

Parts: `OD-C08` with its 2 standoff inserts, OEM power PCB `OD-E01`, 4 × `OD-F02`,
2 × `OD-F11` M3×6, 2 × `OD-F15` ties for the loom slots.

1. Screw the tray to the plate: 4 × M3×8 from above through the flange into the inserts
   at (88 / 106, z −222 / −78). The wall stands at x 73…76, 2 mm from the bulkhead's
   rail.
2. Put the board on edge, solder side toward the tray's wall, with the H1/H2 edge
   (connectors J1…J3) toward the front. Pins on standoffs H5/H6 go through the board's
   holes. Fasten H1 and H2 with M3×6 (`OD-F11`). The spec suggests a plastic or fibre
   washer under each head on the component side (`OD-C08` A-04).
3. The solder side keeps 6.44 of air to the wall. Nothing may touch it except the
   standoffs.
4. **Keep-out:** the tray with the board occupies x 73…112, z −230…−70, y 0…92 (board to
   x ≈ 109.3). Keep wires and other parts out of this box.

### 6.9 Tubing

Follow [WATER_FLOW.md](WATER_FLOW.md) and the donor. Use the OEM tubes with their bushes,
springs `OD-W21`, O-rings `OD-W22` and clips `OD-W23`. Route at room temperature and
with no water in the system.

| # | From → to | Tube |
|---|---|---|
| 1 | tank `OD-W01` → flowmeter `OD-H24` | `OD-W11` (L270), through `OD-C11`'s tube hole |
| 2 | flowmeter → pump `OD-H01` | `OD-H25` |
| 3 | pump → 3-way valve `OD-H22` | TUBE 1 (up to 15 bar) |
| 4 | 3-way valve → thermoblock `OD-H11` | TUBE 2 |
| 5 | 3-way valve → tank (bypass return) | TUBE 3, through `OD-C11`'s other tube hole |
| 6 | thermoblock → connector `OD-H23` port A | TUBE 4 (hot) |
| 7 | connector port C → group head | TUBE 7 (hot) |
| 8 | connector port B | **blanked in v1** with `OD-F05` epoxy (steam is phase 2) |

- Only `OD-W11` and `OD-H25` have been matched to BOM lines. TUBE 1…7 are to be matched
  to `OD-W12`…`OD-W15` during teardown (WATER_FLOW.md). Record the matches you find.
- **TUBE 7** enters the carrier's column through its rear window (x ±10, machine y 40…70),
  rises inside the column, leaves through the hatch and drops into the hub window from
  above to the OEM water connection (`OD-G07` gasket, `OD-H14`, `OD-H15`) on `OD-G04`'s
  hub tube (`OD-C05` A-06, A-07). The lid leaves 37 mm of headroom above the carrier's
  plate for this loop (`OD-C10` A-06).
- The valve's hose ports sit about 16 mm above the plate, with the mount's window open
  below them for the bend (`OD-C07` A-19).
- The anti-drip valve `OD-H21` "sits in the water path, not on the mount" (chassis/README).
  WATER_FLOW.md does not show where. Follow the donor.
- The tank tubes leave through the two Ø12 holes in `OD-C11` at (−100, 30) and (−84, 30)
  (fit them when the back panel goes on, 6.11). The tank dock `OD-C06` is deferred and the
  tank stands on the table; how its seat `OD-W03` is held is not designed yet.
- Leave both drain holes in the plate (−80, −120 and −80, −230) open, and keep tubes off
  them.

### 6.10 Wiring

**No wiring diagram is in the repository yet.** [`electronics/README.md`](../electronics/README.md)
is a placeholder for phase 4. Do not improvise: wire path 1 exactly as the donor was
wired, with the OEM PCB `OD-E01`, the button board `OD-E02` and the OEM looms
`OD-E07`…`OD-E09`. Use your teardown photos and have a competent person check the result
(§2). Use `OD-F06` spades and 105 °C wire only where an OEM loom is too short, and match
the OEM conductor and terminal.

What the chassis provides:

- Four Ø14 wire windows through the bulkhead `OD-C02` (no printed grommets; fit rubber
  grommets or tie the wires clear of the edges, `OD-C02` A-13): (y 150, z −200) pump;
  (y 150, z −130) thermoblock heater and thermostat; (y 150, z −60) group head side;
  (y 60, z −55) valve and flowmeter wires along the front (`OD-C02` A-04).
- Tie slots on `OD-C08` above the board's top edge (two pairs at y 86…90).
- The mains cord `OD-E06` enters through `OD-C11`'s Ø12 hole at (95, 30) in the grommet
  `OD-C14` (6.11).

Rules: the TCO `OD-H18` stays in series in the heater circuit. Earth goes to every metal
part, and you check it with a meter. No mains conductor may touch the board's solder
side or lie on the wet side of the bulkhead.

Not designed yet: the microswitch `OD-E03`, the on/off push button `OD-E04` and the
unipolar switch `OD-E05`. The `OD-C08` spec assigns them to the front panel, but `OD-C09`
has holes only for `OD-E02`'s three buttons. Until a panel revision gives them a place,
decide where they sit with the person doing the electrics.

### 6.11 Back panel `OD-C11` and cord grommet `OD-C14`

Parts: `OD-C11` with its 2 ledge inserts, 2 × `OD-C14`, 4 × `OD-F02`, 1 × `OD-F09`.

1. Thread the tank tubes through the two Ø12 tube holes, and the mains cord's inner end
   through the Ø12 cord hole at (95, 30) from outside.
2. Screw the panel to the plate: 4 × M3×8 from above through the floor flanges into the
   inserts at (±81 / ±95, z −282). Each screw is 5 in front of the top ledge, so a
   straight driver reaches it.
3. Grommet: put the two halves round the cord outside the machine and push them in along
   the cord until the flanges meet the wall. Tie one 4.8 mm tie round the groove just
   inside the wall, **head upward** (away from the gusset below), pull it tight and cut
   the tail. Nothing may sit within 0.5 of the tie head.
4. Check grip: a firm pull on the cord must not move it (`OD-C14` REQ-05, §7.4).

The printed Ø12 holes may come out 0.1…0.2 undersize (`OD-C14` A-01). Ream them rather
than force the grommet.

### 6.12 Front panel `OD-C09` and button board `OD-E02`

Parts: `OD-C09` with its 2 boss inserts, `OD-E02`, 4 × `OD-F02`, 2 × `OD-F13` M3×18.

**Order (`OD-C09` A-14): screw the panel to the plate before the board goes on.** The
board lies over the left flange screws.

1. Stand the panel on the plate's front edge (wall at z +94…+97) and drive 4 × M3×8 from
   above through the floor flanges into the inserts at (±85 / ±95, z +77).
2. With the lid off, offer the button board from behind, its three caps through the three
   Ø15 holes in the left pillar (1 cup at the top, 2 cups in the middle, steam at the
   bottom). Drive the two M3×18 from the board's back into the boss inserts.
3. Connect the board to `OD-E01` with its OEM loom (6.10).
4. Lock the portafilter and check the handle clears the window. At a lock 10° past the
   new-gasket position, the clearance is 2.5. It touches at +12° (`OD-C09` RV01 F2), so
   recheck as the brew gasket wears.

Keep free: the drip tray slot (x ±74.8, y 0…49.8) and the phase-2 steam knob place
(Ø32 about x +95.5, y 140) on the right pillar.

### 6.13 Side panels `OD-C12`, `OD-C13` and brackets `OD-C16`

Parts: 6 × `OD-C16` with their inserts, `OD-C12`, `OD-C13`, 12 × `OD-F02`.

Order (side panels spec, §4): brackets first (lid and panels off), then the panels, then
the lid.

1. Screw the six brackets to the plate: one M3×8 each from above through the bracket's
   counterbore into the inserts at (±104.5, z −262 / −15 / +62). The insert bore in each
   bracket faces outward, toward its panel.
2. Fit the valve (6.7) before the left panel. `OD-C12` has a 0.9 relief over `OD-C07`.
3. Offer each panel from outside against its three brackets and drive 3 × M3×8 from
   outside through the panel's Ø3.4 holes (y 10) into the bracket inserts.
4. Small openings stay at the corners: about 4 at each front corner and about 4 × 4 at
   each rear corner, closed from above by the lid. A small printed cap can close them
   later (chassis/README).

### 6.14 Drip tray and cup rest

Slide the drip tray `OD-C21` (with float `OD-C22` and cup holders `OD-C23`/`OD-C24`)
into the tray slot under the group head. Its zone is x ±75, z −15…+85 on the plate, with
the cup rest top ≤ 36.9 above the plate (`OD-C01` A-06). The tray is not scanned yet
(issue #9).

### 6.15 Lid `OD-C10`

Parts: `OD-C10`, 4 × `OD-F02`.

1. Lower the lid: its side skirts close over the side panels' 60° lips (0.40 per side).
   The front skirt rests on `OD-C09`'s top edge (y 215), with no screws at the front.
   The lid rests on the panel tops.
2. Drive 4 × M3×8 from above through the counterbored columns: two into `OD-C02`'s
   top-rail inserts at (65, z −60 / −210), two into `OD-C11`'s ledge inserts at
   (±90, z −293).
3. The lid's two rest pads stand 0.5 above the carrier's plate, so a hand pressing the
   lid bears on the carrier.

Service: the lid comes off with 4 screws. That gives access to the OPV, the housing
screws and the carrier hatch.

## 7. First power-up and tests

Test in this order. Behind an RCD, with the shield and glasses for anything under
pressure. Stop at the first fault.

### 7.1 `OD-T01` bench pressure test of the ASA housing

Before the housing goes into a machine that will see water, follow
[`chassis/OD-T01_TEST_PROCEDURE.md`](../chassis/OD-T01_TEST_PROCEDURE.md) in full. In short:

- Print the rig in PLA at 100 % infill and screw it to the bench.
- Hang the ASA housing (with its inserts and `OD-G04`) under the plate with
  4 × `OD-F14` M3×10. Snug them, do not crush.
- Feed the hub through the OEM water connection, close the mouth with a blind basket in
  the portafilter, bleed the air out, and use cold tap water only.
- Behind the shield, raise the pressure in steps of 3, 6, 9, 12 and 15 bar, holding each
  for 60 s, then hold 15 bar for 5 min.
- **Stop at once** on a gauge drop, a crack or whitening, a weep at the lugs or inserts, a
  screw head sinking into the plate, or the plate bowing.
- **Pass:** 15 bar for 5 min with no crack, no step on the gauge and no weep at the lugs.

Record what the procedure lists (date, rig version v02, filament, infill and settings,
washers or not, handle angle at lock, gauge readings per step, highest pressure held,
photos before and after). File the result in `chassis/reports/OD-G01_group_head_housing/`
(REQ-12) and `chassis/reports/OD-T01_pressure_test_rig/` (REQ-08).

### 7.2 Cold leak check in the machine

With the ASA housing fitted, the lid off and the machine on its feet, check every joint
of the water path for drips: tube ends, the valve, the flowmeter, the thermoblock
connections, the hub connection and the blanked steam port. Also check that a drip on the
wet side runs to the drain holes and not under the bulkhead (`OD-C02` A-12), and that
nothing collects in the carrier's foot.

**The repository has no cold leak-check procedure yet.** In particular, it does not say
how to run the pump with the OEM board (path 1) without the board also heating the
thermoblock. Agree the method with the person doing the electrics before mains is
applied. Until then, a check without mains is the safe minimum: fill the tank and look
for drips.

### 7.3 First hot run

Only when §7.1 has passed, §7.2 is dry, and `OD-G01`, `OD-C04` and `OD-C05` (and, per
§2, `OD-C02`) are in their service material. The machine must also be checked by a
competent person (earth continuity to every metal part, TCO in circuit, insulation)
and run behind an RCD.

- Heat up with the lid off and watch the thermoblock zone, the mounts and the carrier.
- Pull the first shots with a basket, then look again for leaks hot.
- Take the temperature readings the specs ask for: the front panel's top bar after a
  run of shots (`OD-C09` A-11), under the lid (`OD-C10` A-10), inside the machine at the
  side panels (`OD-C12`/`OD-C13` A-08), and the carrier's column if TUBE 7 warms it
  (`OD-C05` RV02 F1).

### 7.4 What to record so parts can move to `validated`

`validated` needs a print and a fit check by the Usta, and for the group head the
`OD-T01` test (chassis/README). File the record under `chassis/reports/<part>/`, with a
photo of the fit, and update the part's `status` in `docs/bom.csv` in the same PR
(CONTRIBUTING).

| Part | Bench row | What to check and record |
|---|---|---|
| `OD-G01` | REQ-12 brew load (Hard) | the `OD-T01` result (§7.1) |
| `OD-T01` | REQ-08 strength | no visible yield or crack at 15 bar |
| `OD-C01` | REQ-09 flatness | warp of the printed plate, and whether the mounts seat without rocking |
| `OD-C02` | REQ-09 stiffness | no rattle or visible flex with the panels on |
| `OD-C03` | REQ-09 vibration | vibration passed to the chassis with the sleeve fitted, at the first run |
| `OD-C04` | REQ-08 heat | the mount holds the thermoblock through a heating cycle without softening (service material only) |
| `OD-C05` | REQ-09 stiffness | lock the portafilter and push the handle: no visible flex |
| `OD-C08` | REQ-06 plug push | the board does not flex when a faston is pushed onto the farthest tab |
| `OD-C09` | REQ-08 stiffness | no visible flex under a button press or with the pump running |
| `OD-C10` | REQ-08 stiffness | the lid does not sag or rattle |
| `OD-C11` | REQ-09 stiffness | the panel does not drum or flex |
| `OD-C12`, `OD-C13` | REQ-08 stiffness | no flex or drumming with the lid on; a hand on a side does not shift the lid |
| `OD-C14` | REQ-05 grip | the tied grommet holds against a firm pull and does not turn |
| `OD-C15` | A-06, A-07 | the nut grips in its pocket; the screw has not loosened after a month |
| `OD-C07` | A-15, A-19 | the hooks snap without cracking; the hoses bend without kinking |

With each record, list the caliper readings that close the part's assumptions (§8).

## 8. Open items

These are assumptions the Usta still has to confirm with calipers, a print or a
decision. Each is OPEN in the part's spec §6 unless noted. The specs have the full
lists.

**All parts**

- Scan scale and units are unconfirmed on every scanned OEM part. Calipers are needed on
  every interface.
- The M3 insert datasheet (5.7 long, Ø4.6 in a Ø4.0 hole) is unconfirmed.
- The K1C and Kobra Max 3 build volumes are not in the machine files.
- The Usta still has to name the service filament for each part.

**`OD-G01` group head housing**

- Calipers or a protractor on the donor cup: lug inner radius 31.68 (A-02), bore 37.10
  (A-03), lug angles (A-04), lug underside profile (A-05), stop block (A-06), shelf
  −14.10 (A-07), pocket and lip ring (A-08, A-09).
- `OD-G04` screws Ø3.5 assumed (A-26), ear geometry and pitch (A-19, A-25), brewing
  gasket compression (A-27, needs `OD-G02` measured).
- Brew load (A-21): needs the `OD-T01` test.
- Spec 1.4 (the corrected sentence that the axis is vertical) awaits ratification.

**`OD-C01` base plate**

- Revision B: the OD-C07 holes leave a 5.0 web to the plate edge, now in PLA (RV02 F5);
  the back panel takes the rear 25 of the tank zone (RV02 F2).
- The machine layout (group head vertical, housing rear face 205 above the plate, pump
  and thermoblock poses) awaits the Usta's confirmation (A-01…A-03, A-16).
- Drip tray zone (A-06; tray scan, issue #9), drainage (A-13), flatness (REQ-09).

**`OD-C02` bulkhead**

- The M3×12 ends exactly on the bore floor (A-03, RV01 F2). Window use and grommets
  (A-04, A-13) are open, and so is drainage (A-12).

**`OD-C03` pump cradle**

- Coil Ø47.3 (A-02), sleeve OD 53.3 (A-03, no input gives it), frame side plates
  (A-04), tie path (A-07), and whether the pump is an EP5 or an EX5 (A-15).

**`OD-C04` thermoblock mount**

- Thermoblock screw holes (A-03) and screw type and length (A-04: Ø3.5 self-tapping
  vs. chassis/README's M3).
- Spacer lengths 10.10 / 37.70 and the 10.10 air gap (A-05).
- NTC and TCO brackets `OD-H17`/`OD-H19` are not scanned (A-06).
- The `OD-H11` STEP is not a valid solid (A-14).

**`OD-C05` group head carrier**

- Group head height (A-03).
- The water connection parts must fit within r 30 of the axis (A-06, not scanned).
- TUBE 7 route (A-07).
- A drain for the foot trough (RV02 F2).
- The counterbore floors' named exception must be signed (F4).
- The ≥ 210 mm driver (F5).

**`OD-C07` valve and flowmeter mount**

- Ear holes (A-02), flowmeter cup and flange (A-06: cup ≈ Ø31.5, flange ≈ Ø40.6, rim to
  flange top 19.9) and base pins (A-07).
- OPV position (A-10).
- The snap-hook strain limit was set for PETG (A-15); the part is now PLA.
- Hose bend space (A-19).

**`OD-C08` electronics bay tray**

- Board hole pitch H1–H2 and H5–H6 by calipers: the pins tolerate about 0.03 (A-02,
  RV01 F4).
- The board's solder side (A-05).
- Wiring, mains entry and venting (A-11).

**`OD-C09` front panel**

- `OD-E02` geometry (A-03) and the button layout (A-04).
- Portafilter lock angle (A-05, RV01 F2).
- Top-bar temperature (A-11).
- No place yet for `OD-E03`…`OD-E05`.

**`OD-C10` top panel**

- Headroom for the tube loop (A-06) and the temperature under the lid (A-10).

**`OD-C11` back panel**

- Cord (A-03), tank tubes in hand (A-04), venting at the first power-on (A-06), and
  clearance to the pump's rear end (A-07).

**`OD-C12`, `OD-C13`, `OD-C16` side panels and brackets**

- Rear corner gap (A-03), the temperature inside the running machine (A-08), the lip fit
  of 0.40 (A-14), and the bracket count of 6 instead of the BOM's old 16 (A-15).

**`OD-C14` cord grommet**

- The Ø12 hole may print undersize (A-01).
- Is the Usta's Ø7.0 cord reading the jacket diameter? (A-02)
- Squeeze when tied (A-05).

**`OD-C15` foot**

- TPU 95A in the spec vs. PLA for now (A-03).
- Machine mass taken as ≤ 8 kg (A-05).
- Nut pocket fit (A-06) and clamp creep (A-07).

**`OD-T01` rig**

- Strength (A-02), bench fittings (A-04), blind basket (A-06), bench fixing (A-11), and
  the pair-B screw heads ≤ Ø17.7 (A-12).

**Not yet designed or documented**

- Wiring diagram (`electronics/`).
- Tank dock `OD-C06` (deferred).
- Places for `OD-E03`…`OD-E05`.
- Matching TUBE 1…7 to `OD-W12`…`OD-W15`, and the position of `OD-H21`.
- A cold leak-check procedure for path 1.
- Corner caps.

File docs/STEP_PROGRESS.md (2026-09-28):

# Scan → STEP progress

Scan to STEP progress board

The board is **generated** from the `status` column of [`bom.csv`](bom.csv). To move a part along, change its status (`todo` → `scanned` → `modeled` → `validated`) and run:

```
python tools/build_bom.py
python tools/build_progress.py
```

Commit `bom.csv`, `BOM.md` and `img/step_progress.svg` together. CI fails if the board is stale.

| Stage | Done when | Lives in |
|---|---|---|
| 1. Scan | Raw STL/PLY + `calipers.md` + photos merged | `scans/OD-Xnn_<name>/` |
| 2. STEP rebuild | Clean parametric STEP, not a mesh export | `step/OD-Xnn_<name>.step` |
| 3. Deviation gate | Two-way CAD ↔ scan deviation report | `step/reports/OD-Xnn_<name>/` |
| 4. Check-fixture | Printed fixture fits the real part (photo in PR) | `step/OD-Xnn-FX_<name>_fixture.step` |

## Work in progress

Real part → 3D scan → open STEP

In the overlays, grey is the rebuilt STEP and red is the raw scan. Where both show, the CAD sits on the scan surface.

| `OD-H01` ULKA EP5 pump: modeled | `OD-H11` Thermoblock: modeled | `OD-H24` Flowmeter: modeled | `OD-H22` 3-way valve: modeled |
|---|---|---|---|
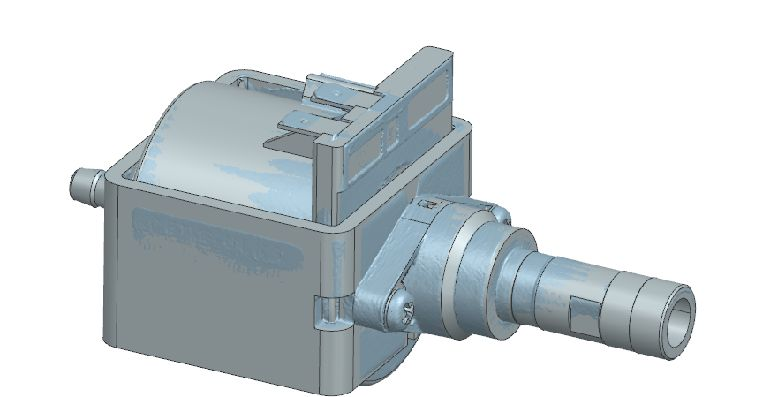
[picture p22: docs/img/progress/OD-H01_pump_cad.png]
OD-H01 ULKA EP5 pump
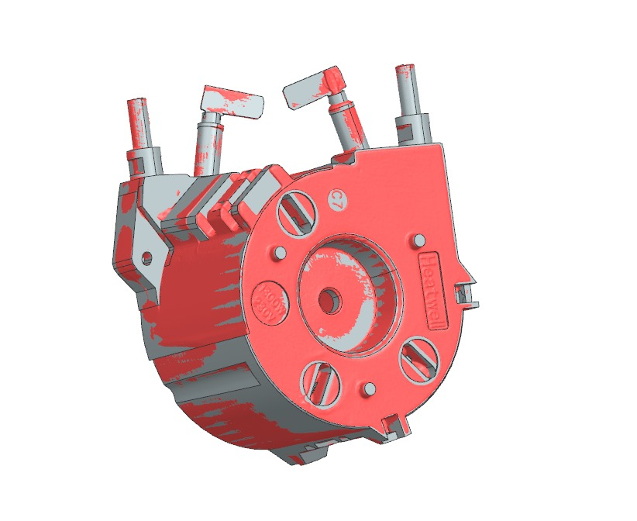
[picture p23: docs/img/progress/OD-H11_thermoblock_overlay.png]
OD-H11 Thermoblock
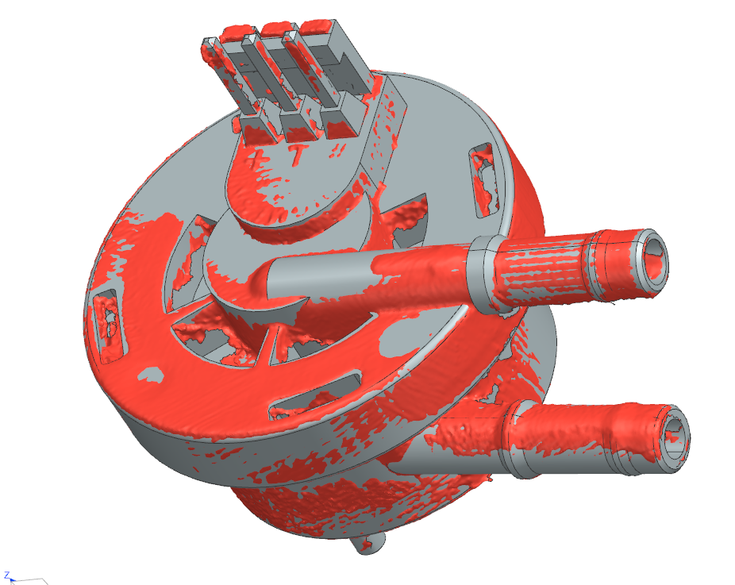
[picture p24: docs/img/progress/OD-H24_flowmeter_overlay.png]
OD-H24 Flowmeter
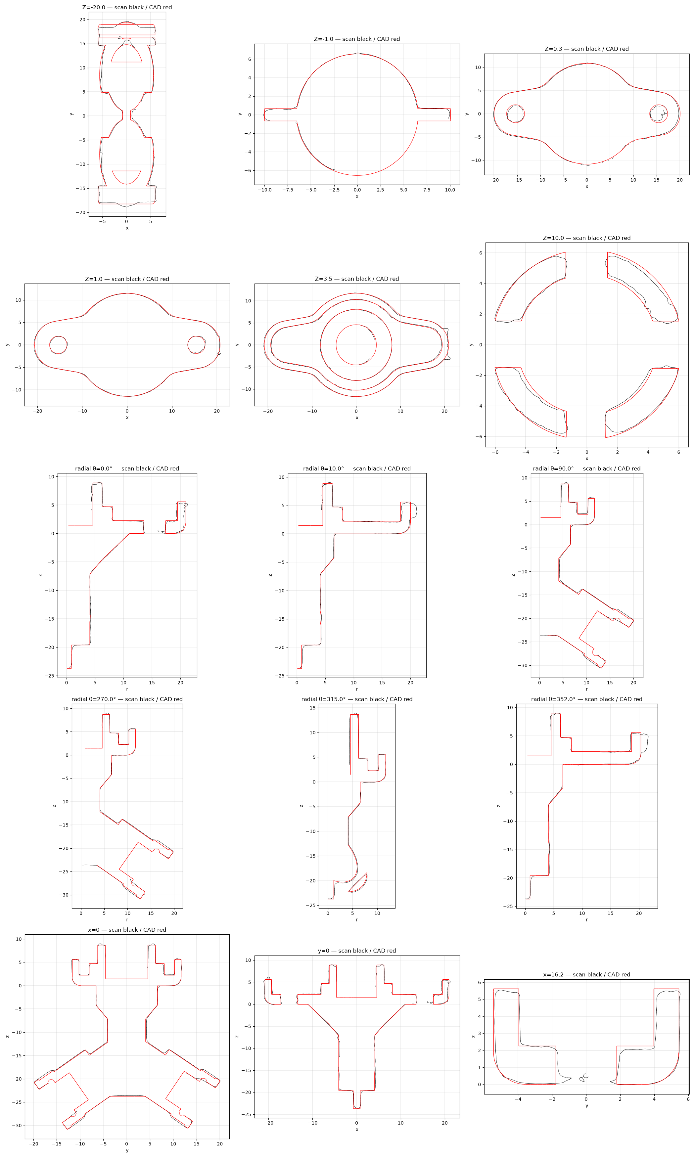
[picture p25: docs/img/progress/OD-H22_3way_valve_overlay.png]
OD-H22 3-way valve
|  |  |  |  |
| [report](../step/reports/OD-H01_ulka_ep5_pump/) | [report](../step/reports/OD-H11_thermoblock/) | [report](../step/reports/OD-H24_flowmeter/) | [report](../step/reports/OD-H22_3way_valve/) |

| `OD-G04` Brewing gasket support: modeled | `OD-S03` Steam knob: modeled | `OD-E01` Power PCB: modeled | `OD-E02` Control button board: modeled |
|---|---|---|---|
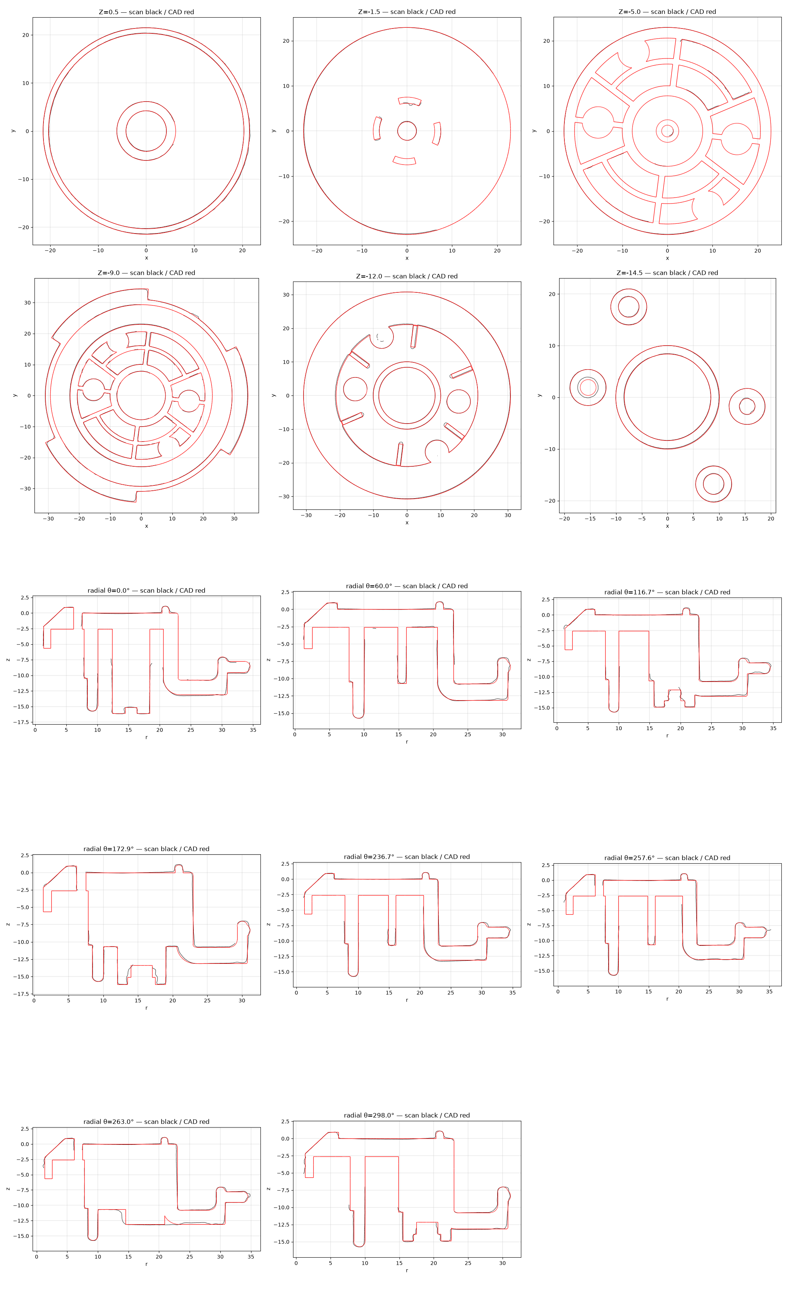
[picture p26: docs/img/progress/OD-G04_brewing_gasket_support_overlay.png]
OD-G04 Brewing gasket support
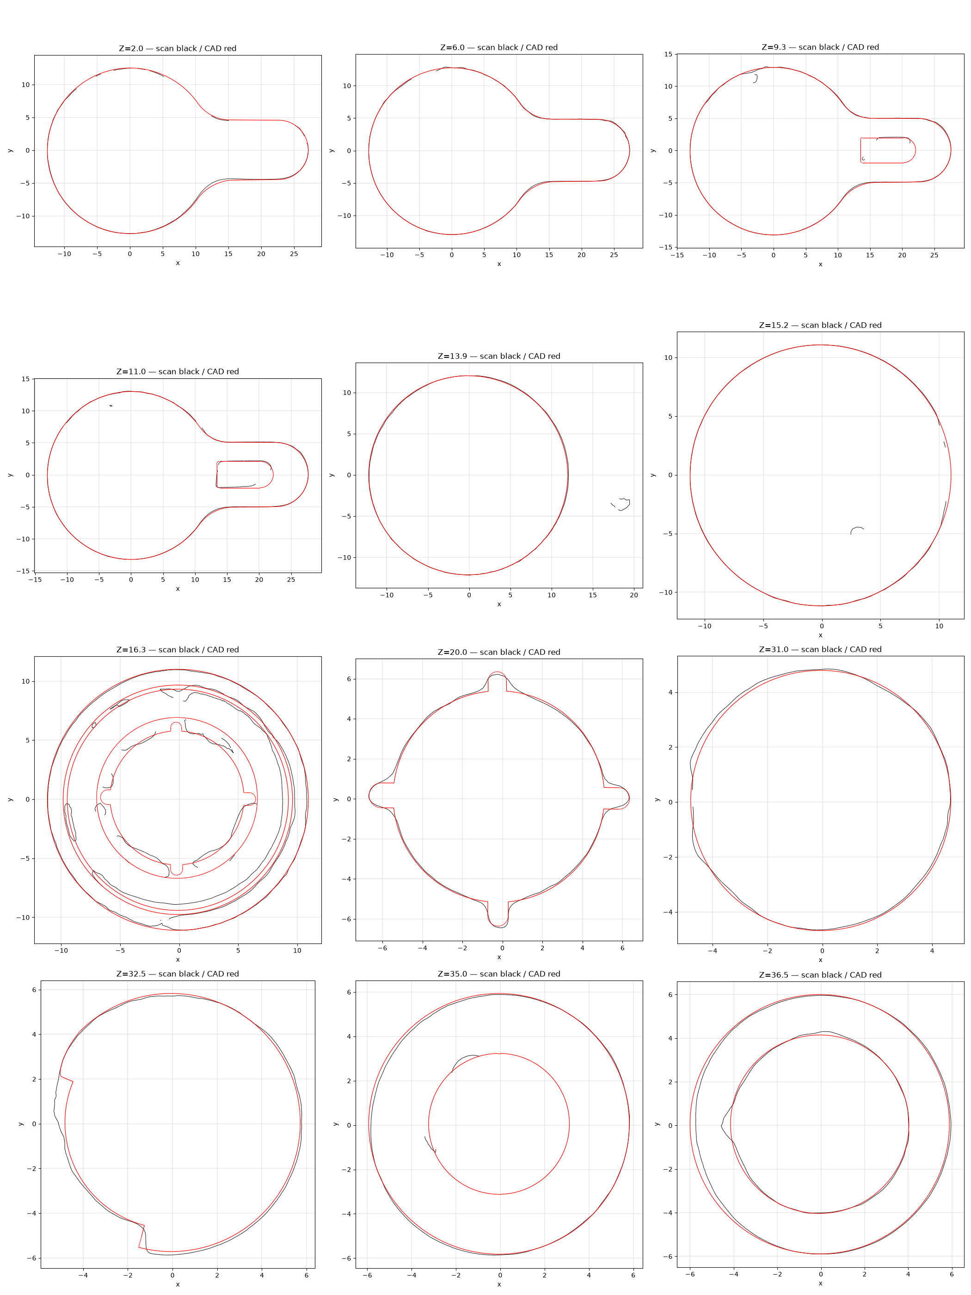
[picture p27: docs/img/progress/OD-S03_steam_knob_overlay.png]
OD-S03 Steam knob
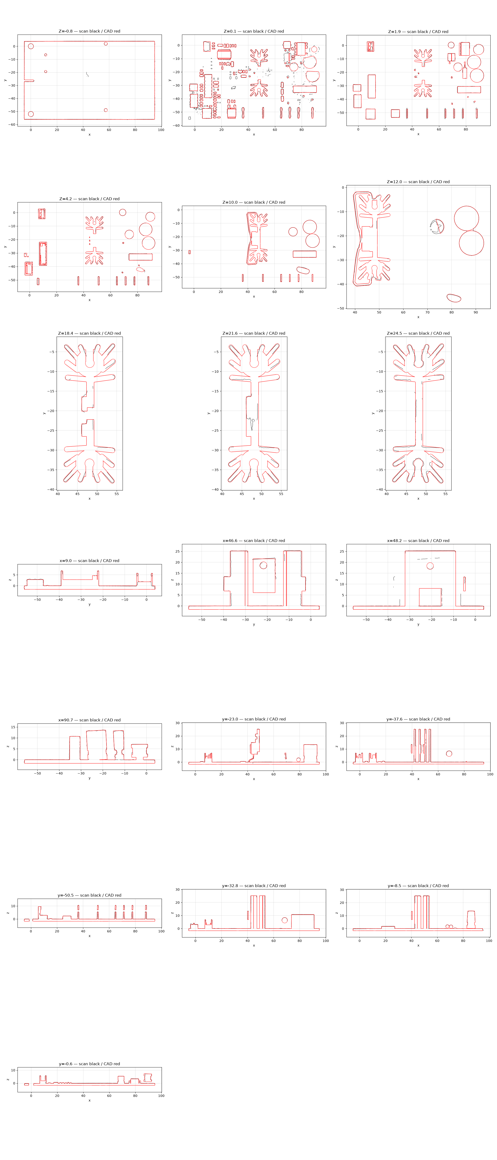
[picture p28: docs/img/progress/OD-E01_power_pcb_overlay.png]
OD-E01 Power PCB
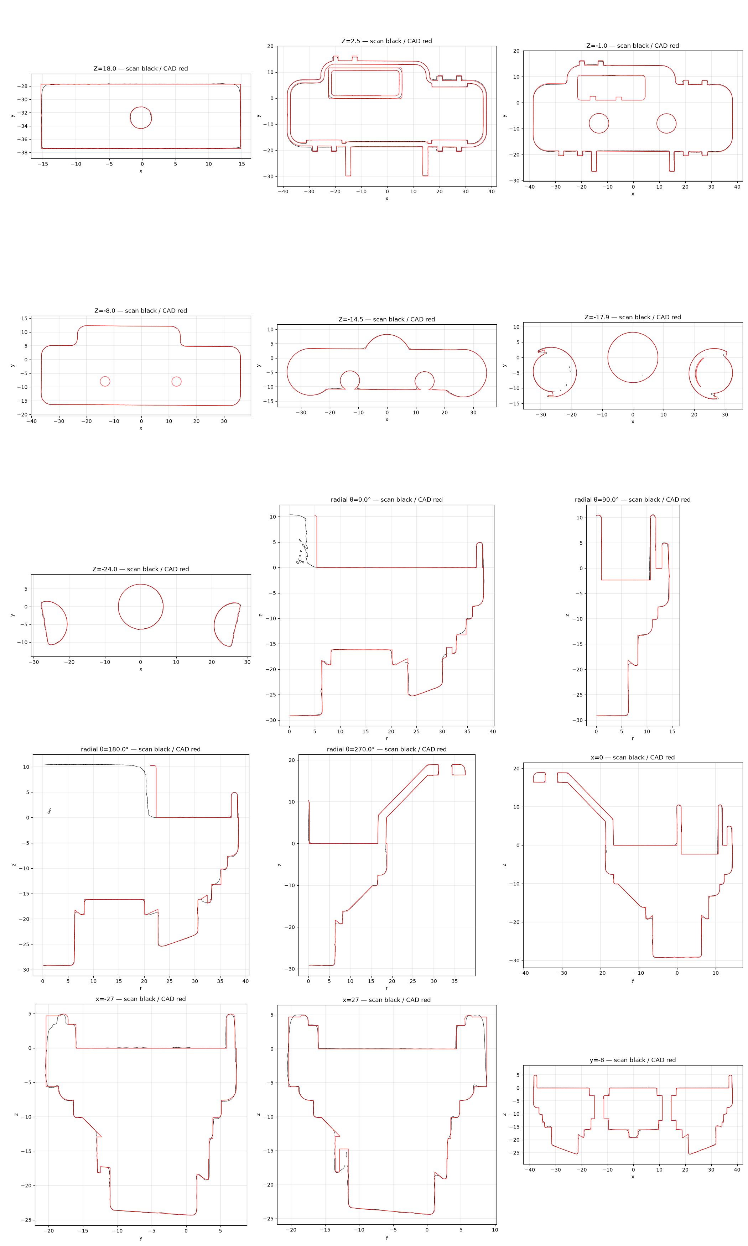
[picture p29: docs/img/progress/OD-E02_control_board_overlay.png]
OD-E02 Control button board
|  |  |  |  |
| [report](../step/reports/OD-G04_brewing_gasket_support/) | [report](../step/reports/OD-S03_steam_knob/) | [report](../step/reports/OD-E01_power_pcb/) | [report](../step/reports/OD-E02_control_board/) |

| `OD-S01` Steam valve: modeled | `OD-S02` Steam wand: modeled | `OD-W03` Tray gasket (tank seat): modeled | `OD-G09` Group head bayonet cup: modeled |
|---|---|---|---|
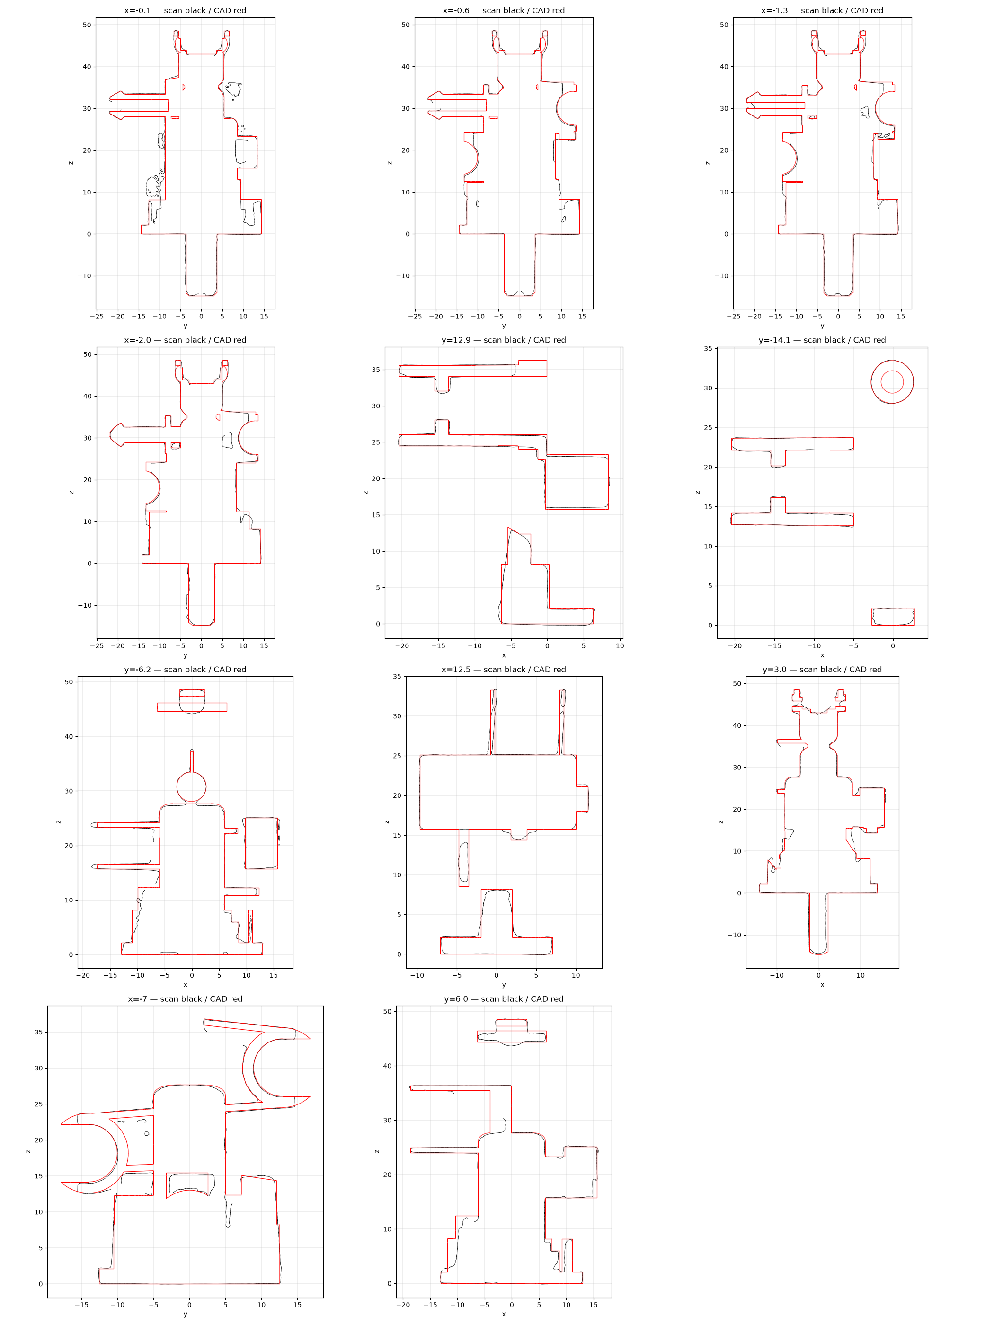
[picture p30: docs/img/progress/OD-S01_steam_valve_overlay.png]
OD-S01 Steam valve
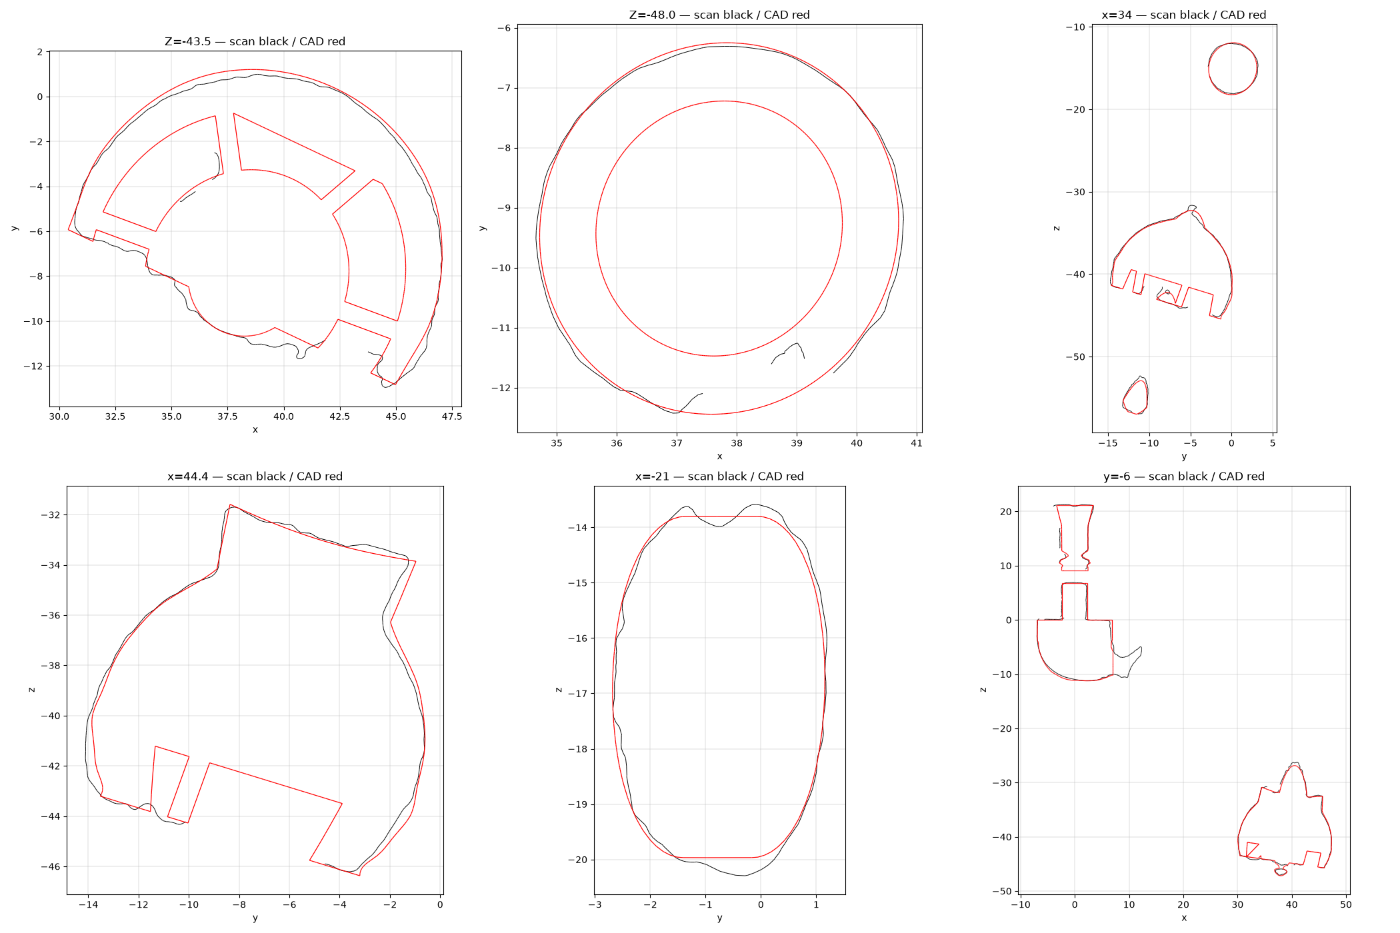
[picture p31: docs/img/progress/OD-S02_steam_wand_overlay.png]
OD-S02 Steam wand
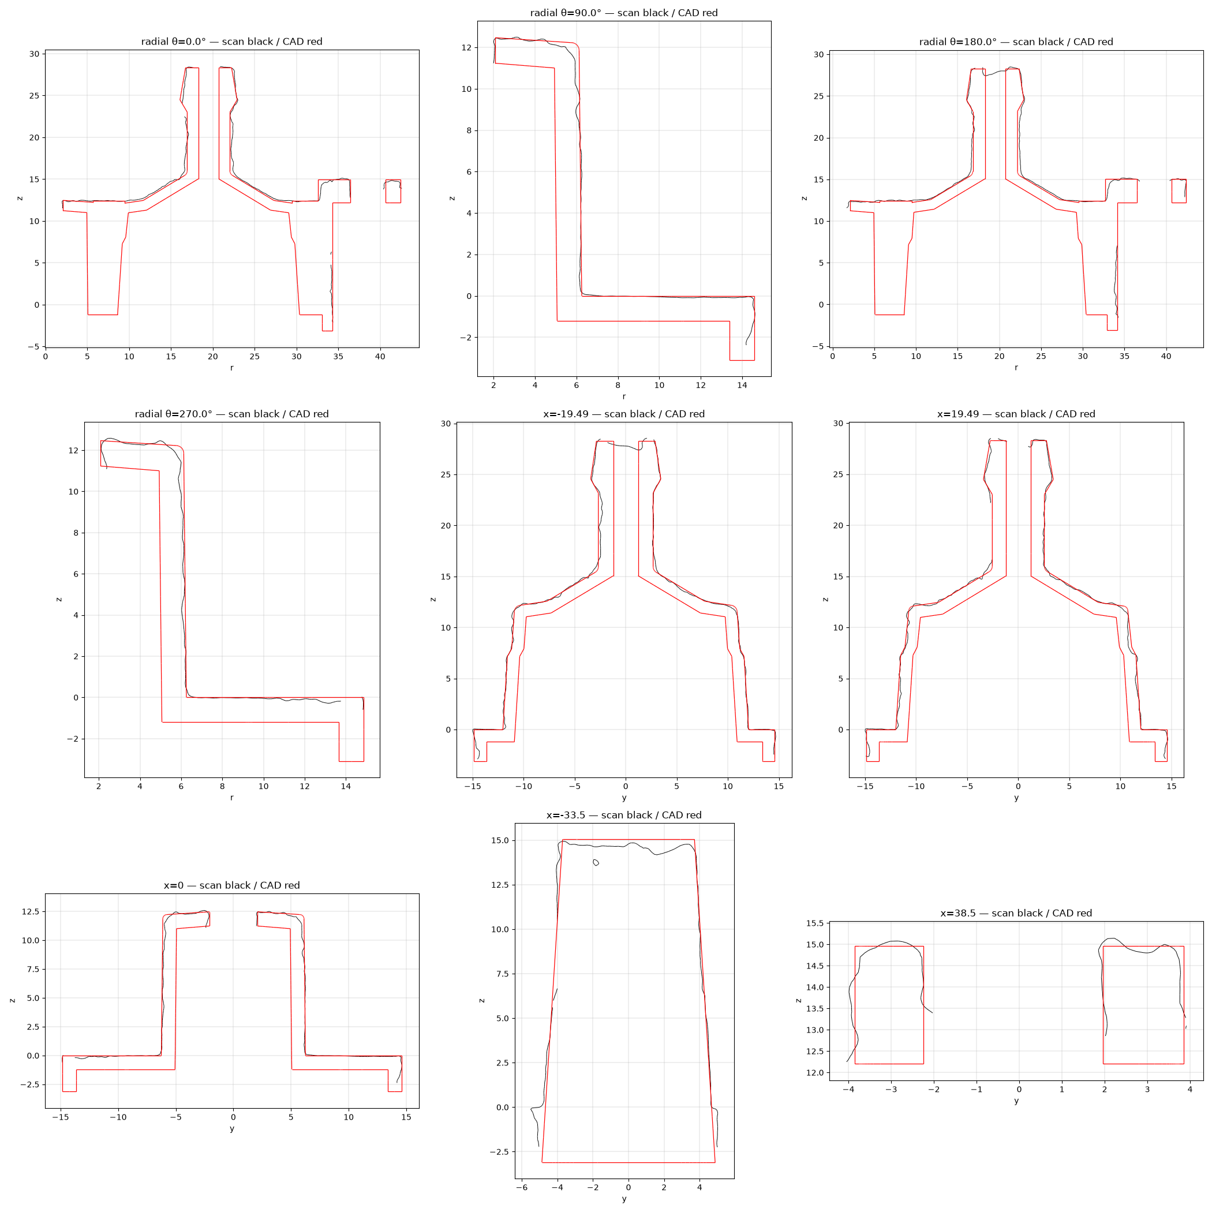
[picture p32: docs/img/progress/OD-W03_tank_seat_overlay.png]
OD-W03 Tray gasket (tank seat)
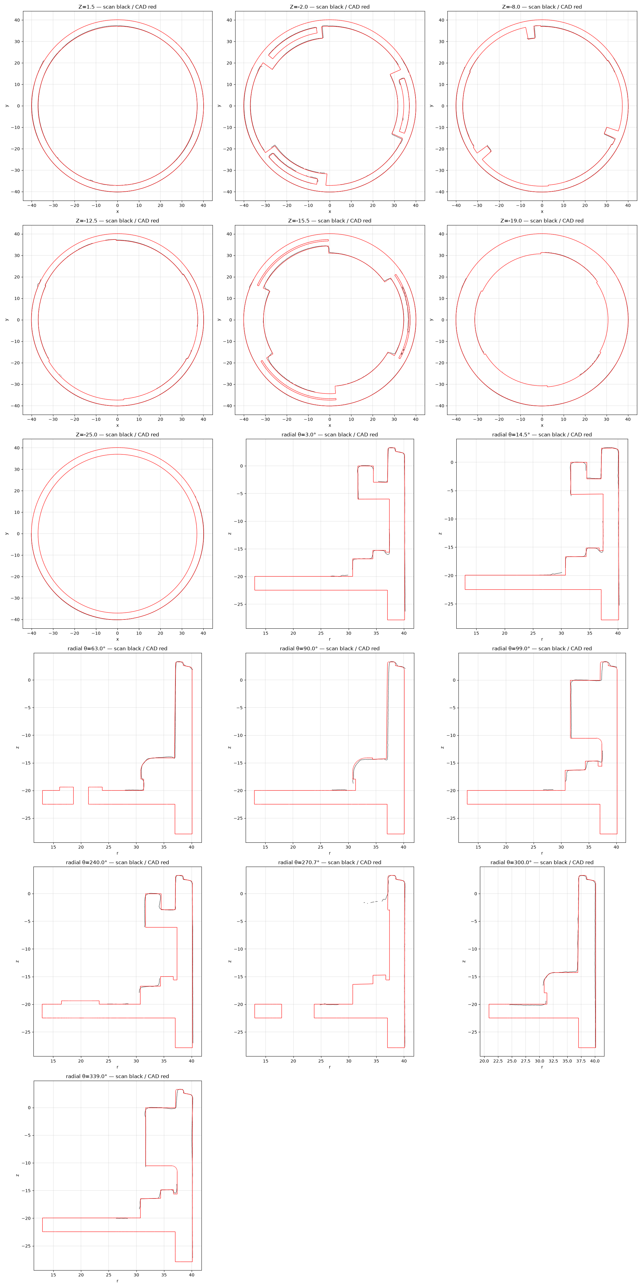
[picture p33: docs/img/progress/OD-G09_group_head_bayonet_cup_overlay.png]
OD-G09 Group head bayonet cup
|  |  |  |  |
| [report](../step/reports/OD-S01_steam_valve/) | [report](../step/reports/OD-S02_steam_wand/) | [report](../step/reports/OD-W03_tank_seat/) | [report](../step/reports/OD-G09_group_head_bayonet_cup/) |

| `OD-G10` Portafilter: modeled | `OD-H21` Anti-drip valve: modeled |
|---|---|
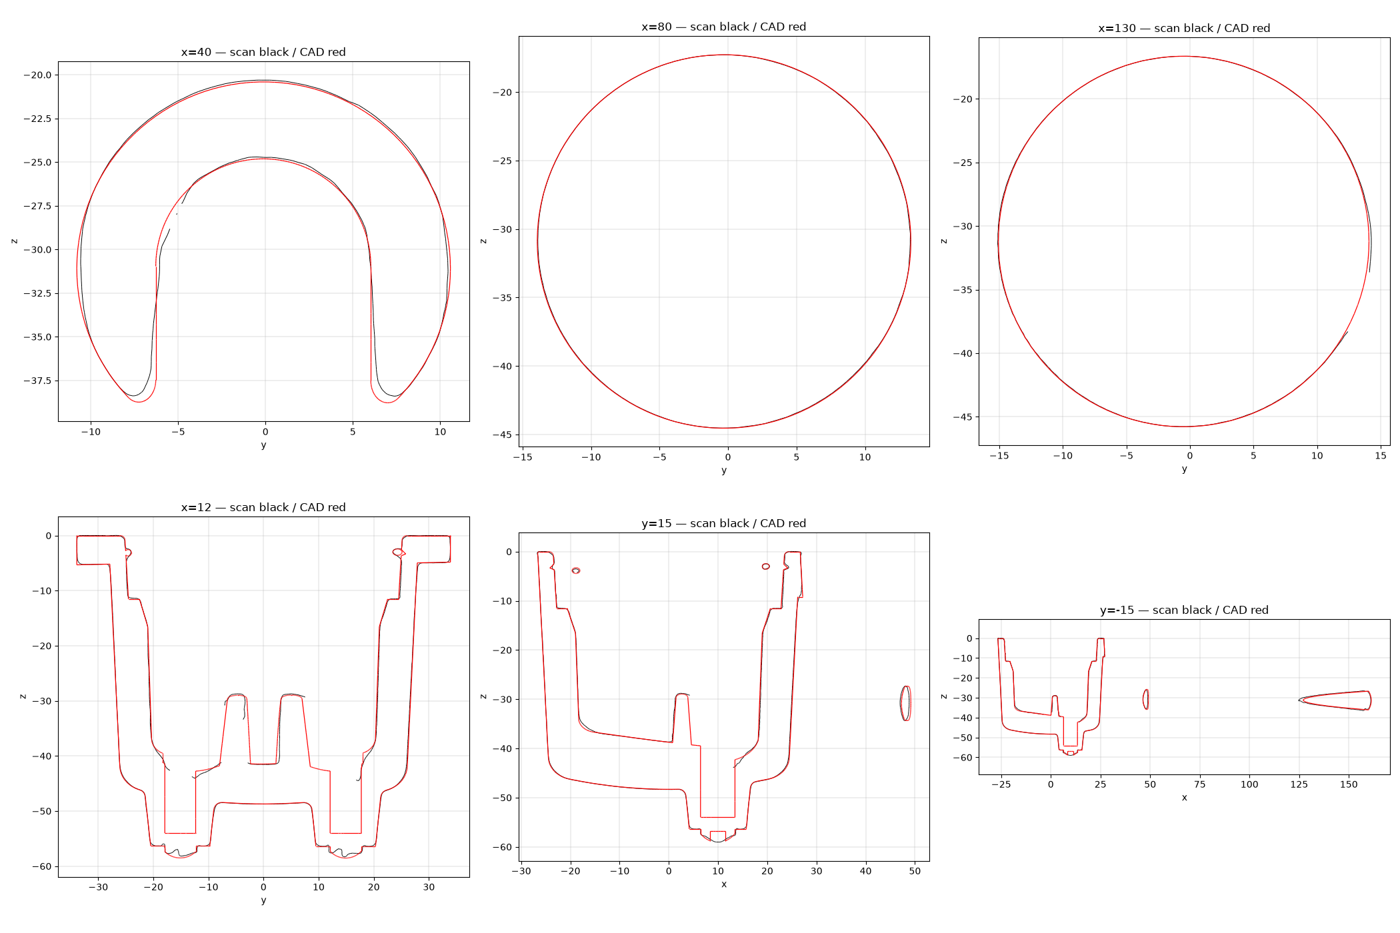
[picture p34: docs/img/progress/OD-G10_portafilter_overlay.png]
OD-G10 Portafilter
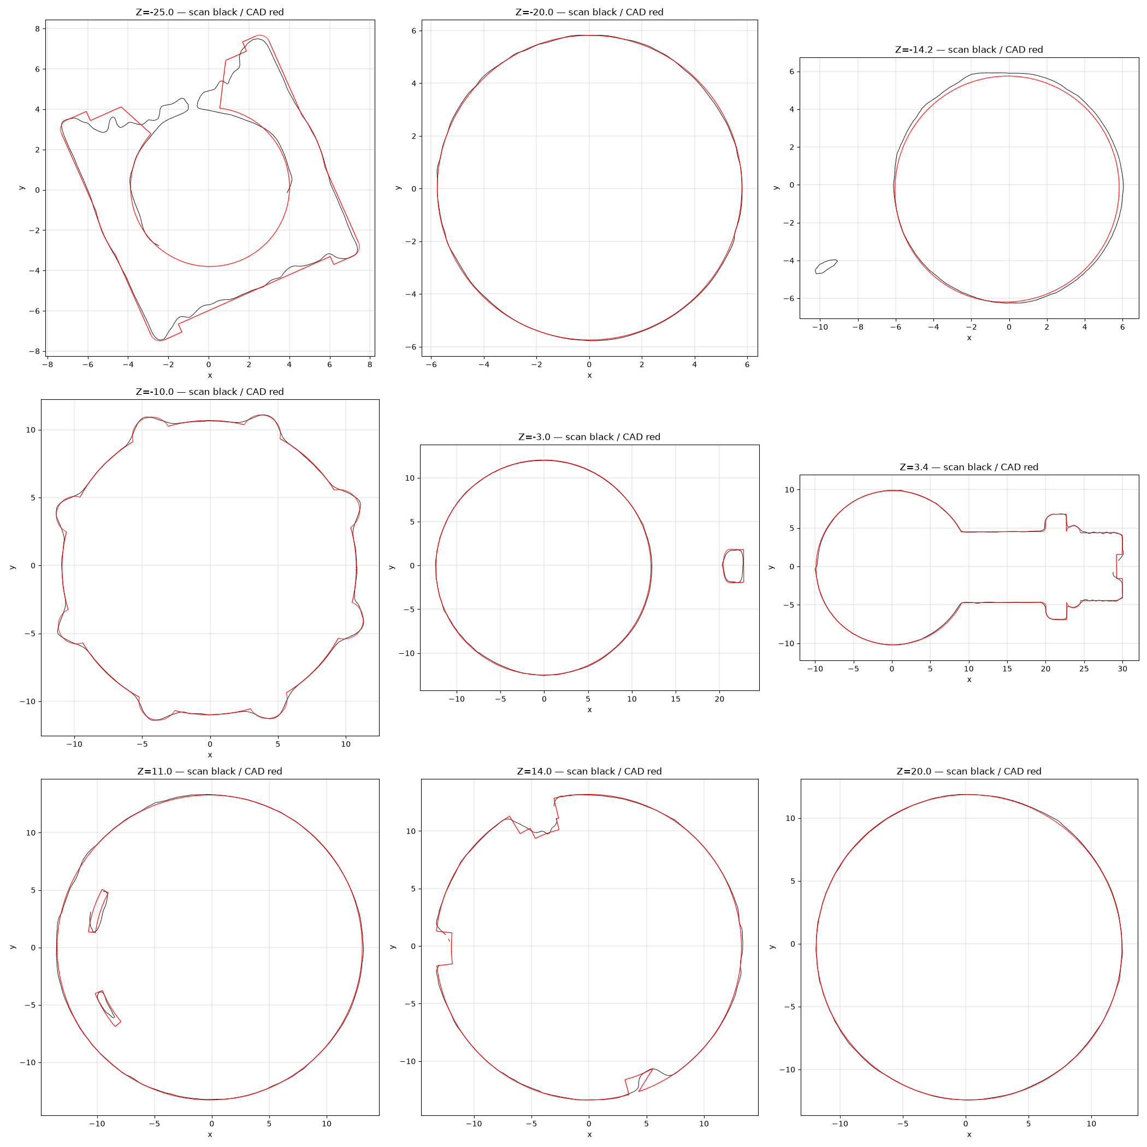
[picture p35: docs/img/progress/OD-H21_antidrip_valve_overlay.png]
OD-H21 Anti-drip valve
|  |  |
| [report](../step/reports/OD-G10_portafilter/) | [report](../step/reports/OD-H21_antidrip_valve/) |

## Parts on the scanner

Donor parts on the scan turntable, matched to BOM numbers. All matches are confirmed.

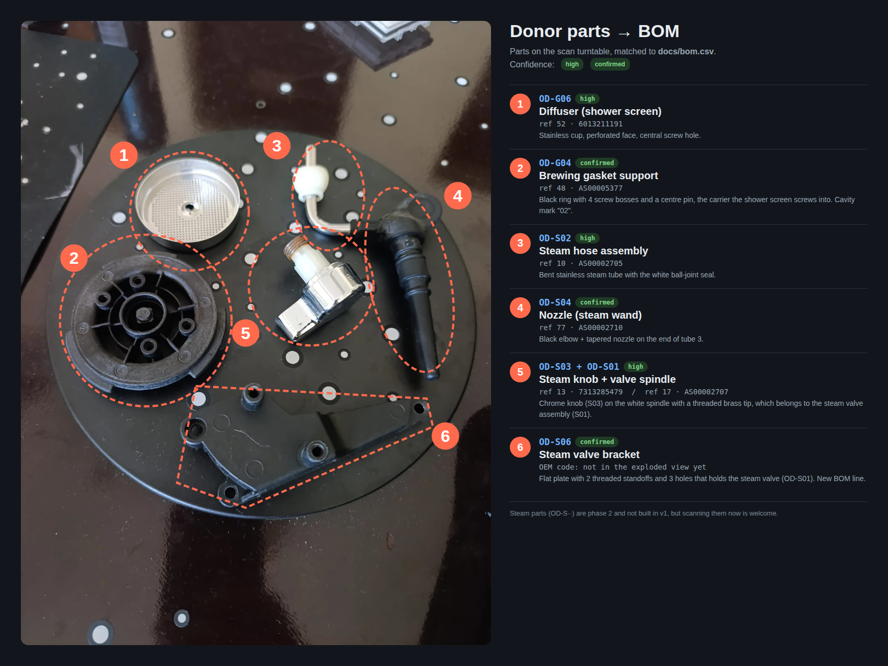
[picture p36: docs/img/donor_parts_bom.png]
Donor parts matched to BOM numbers


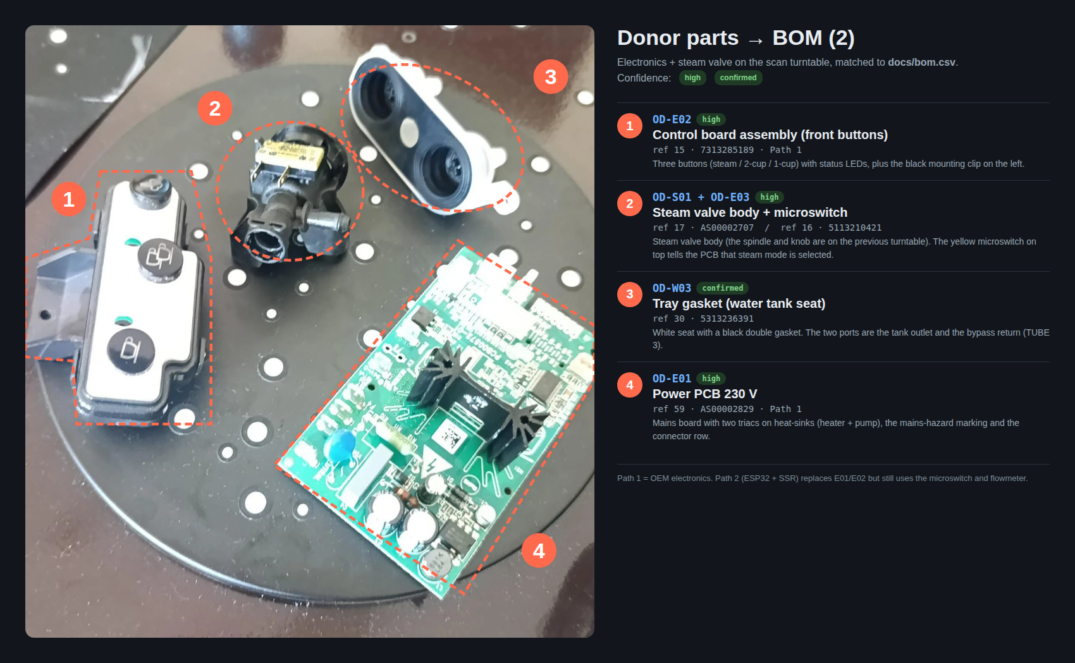
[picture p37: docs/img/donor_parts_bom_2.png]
Donor parts matched to BOM numbers, electronics and steam valve


Next up: check-fixtures for every modeled part (stage 4). Every part still marked `open` in stage 1 needs someone with the part to scan it. See [CONTRIBUTING.md](../CONTRIBUTING.md).

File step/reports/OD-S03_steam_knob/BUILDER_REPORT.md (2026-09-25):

# BUILDER REPORT: OD-S03_steam-knob (stl-re skills, builder stages only)

Stages run: intake → measure → rebuild (orchestrate §2). `intake*` was skipped because the run is
scan-only (DECISIONS.md MEASUREMENTS). Verify and deliver were **not** run (CHK-INDEP). There is no
`qa/` output and no `deliver/`. Nothing below is a gate verdict.
Regime: baseline-skill, plastic, p95 ≤ 0.30 / max ≤ 0.80 mm (`intake/regime.json`, written by
`intake.py regime`). `init_run.py status`: intake, measure and rebuild are complete. The input
sha256 is unchanged (`ce4a9dfc…`).

## 1. Intake (`intake/`)
- `intake.py stats`: 363,988 faces, 1 body, open (1,202 boundary edges in 17 loops, which are
  chrome scan holes). Ray-vote orientation: outward. **No decimation**, so `work.stl` is the
  full-resolution mesh.
- Datum (`alignment.json`, status **OK**):
  - Primary: the cap crown face → z = 0, with +Z toward the sleeve. rms 0.0146 against a plane
    noise of 0.0187, measured on the lever −Y flank (independent, not self-referential).
    The first run used the default 10° cone and read 0.0216 → **STOP**. The excess comes from the
    onset of the crown edge round; the seed sweep 0–5 was stable, so it was not a tie. I re-ran
    with `cone_deg: 3` (evidence `intake/alignment_attempt1_STOP.json`; DECISIONS OTHER).
  - Secondary: sleeve-envelope Kåsa sections + cap-wall IRLS. Median rms 0.0431 against a circle
    noise of 0.0436.
  - Clock: the lever goes to +X via `fourier_mass` n = 1, **area-weighted** through a scratch
    wrapper (defect D1). After the fix, the two flank planes read −0.64° / +1.03° about +X.
  - CHK-TILT: a finding, not resolvable (see D3). CHK-SCALE: FLAG.
- `INTAKE_CARD.md` has feature list E01–E20 (CHK-ENUM). `MEASUREMENTS.md` is the request, with
  scan-predicted values and every row ABSENT. `coverage.json` and `noise_*.json` are written.

## 2. Measure (`measure/params.json`, 71 params; `PARAM_TABLE.md` validator: 0 errors, 0 warnings)
- Scripts are in `measure/figures/src/`: `axes.py`, `stations.py`, `measure_all.py`, `jog.py`,
  `thread.py`, `lever.py`, `pocket.py`, `ribs.py`, `rib_tip.py`, `stem_base.py`, and
  `build_params.py`. `build_params.py` builds params.json from the JSONs, so no number is retyped.
- Sub-body axes are kept as measured positions in the frozen frame:
  - Cap: (0.032, −0.095). Tilt 0.07°, so it is Z-parallel.
  - Collar: (−0.117, −0.047).
  - Stem group (core, neck, sleeve, bore): one line through 20 station centres, tilted **0.754°**
    (residual rms 0.042). It sits 0.1–0.3 mm off the cap axis, which fits a cap + stem + sleeve
    assembly.
- Key values (mm/deg):

  | Param | Value | Rule |
  |---|---|---|
  | cap_R_z0 | 12.530 | keep-measured |
  | draft | 3.006 | mean-of-n of cap/flanks |
  | crown_round_R | 2.459 | mean-of-n |
  | step_z | 13.689 | mean-of-n |
  | collar_R | 11.116 | keep-measured |
  | stem core R | 5.317 → 5.159 | keep-measured |
  | neck_R | 4.736 | keep-measured |
  | rib_count | 4 | FFT order 4 at 3 stations, **CHK-COUNT pass** |
  | rib_theta_deg | −0.9 / 90.7 / 179.4 / −90.4 | keep-measured |
  | rib_width | 1.07 / 0.92 / 1.24 / 1.02 | keep-measured, tip full round |
  | pocket floor | 8.535 | keep-measured (floor seen by 64 faces) |
  | bore_R | 4.088 | keep-measured, critical |

- **Sleeve (thread) findings.** The ripple is **planar rings**, not a uniform helix:
  - Pitch 1.231, crest R 5.952, arc ρ 1.137, depth 0.181 (scanner-smoothed).
  - The crossover is at both ends: the bottom edge rises 1.059 over 132.6°→255.4° and the top
    edge rises 0.908 over 124.6°→245.4°. Both are right-hand, each ends in a step, and the fit rms
    is 0.073 / 0.056. This fits a formed coil.
  - The pitch, crest and bore values are critical, with a re-run trigger.
- Checks:
  - CHK-COUNT: pass.
  - CHK-CLUSTER: pass. The bore cluster is the planned shoulder E19. The E20 bore notch (≈0.5 deep)
    is declared.
  - CHK-FRAME: pass.
  - CHK-ACHIEVABLE: did not run; there are no readings.
- 16 simplifications are declared, each with its measured cost. There are 4 open questions.

## 3. Rebuild (`build/`)
- `MODELING_PLAN.md` was written first; the F01–F15 feature list maps E01–E20. `model.py` is
  params-driven, all params are used, and it has no geometry literals beyond the documented
  clearances OV 0.5, CUT_OVER 1.0 and EPS 0.02.
- Construction steps:
  - Cap cylinder ∪ lever outline (tip arc tangent to the flanks).
  - 2 blend fillets, then ONE `draft()` → planes and cones.
  - Crown round and step-edge round as loop fillets.
  - Drafted slot pocket.
  - Collar, stem and spigot revolves; the crest arcs are tori.
  - 4 ribs: slot section extruded along the measured tip line.
  - **Real helical geometry**: two helical sweeps, a bottom-ramp cut and a top tail. These gave a
    valid single solid.
- Result:
  - **1 valid closed solid in both frames.**
  - 88 faces, against a plan range of 85–160.
  - Volume **11,657.12 mm³**.
  - Surface types: plane 34, cone 15, torus 17, cylinder 11, revolution 1, B-spline 10. The
    B-splines are only on the helical ramps (1.4 % of area); the analytic area share is 0.986.
  - Fillets: 4 OK.
  - Exports: `_datum.step`, `.step` (scan frame), `_cad.stl`, `export_check.json` (pass,
    frames agree), `face_stats.json`, `fillets.json`, `build_log.txt`.
- There were 2 builds in one iteration. Build 2 only moved the tail tool EPS inside crest_R, to
  remove a 1e-6 mm² sliver face.

## 4. Builder self-check (NOT QA)
Full-res scan, scan frame, 200k seeded samples, unsigned distances; script
`build/selfcheck_NOT_QA.py`.

**scan→CAD:**

| rms | p50 | p95 | p99 | max |
|---|---|---|---|---|
| 0.110 | 0.030 | **0.178** | 0.353 | **2.302** |

1.5 % of samples are above 0.3 and 0.22 % are above 0.8.

- **Max cluster:** 392 samples at r 10.7–12.1, z 6.9–11, θ 100–108°. This is inside the cap wall,
  in intake hole B, and looks like bridged or collapsed chrome skin; the photos show an intact cap.
- **Second cluster:** the stem/collar crevice, r 5.25–6.2, z 15.0–16.0, θ −135..−45°, max 1.07
  (43 samples). The crevice floor depth varies about ±0.6 mm around θ.
- **Zone p95:** collar/grooves 0.347 (above the band locally), neck 0.232, sleeve 0.186, all other
  zones ≤ 0.16.

**CAD→scan raw:** p95 0.481. This includes the unscanned interior and the scan holes.

Expected verdict risk: the p95 band is likely met; **max 0.80 is likely missed** because of the
hole-B artefact and the crevice.

## 5. Skill/script defects found (repo not modified)
- **D1** `stl-re-intake-datum/scripts/align.py:247-259` (the phase at :255): `fourier_mass` sums
  vertex counts. It was biased 3.8° here by scan vertex density and holes. Workaround:
  `intake/workaround/align_areaw.py` monkeypatches only this branch to area-weighted face centres
  (DECISIONS OTHER).
- **D2** `align.py:366`: the axis-primary crop is an infinite radial cylinder, with no z window. On
  a stepped part it cannot "crop to one clean cylinder" as the skill requires. I used a plane
  primary instead.
- **D3** `align.py:102` (`wall_face_stations`): there is no θ exclusion. One-sided lever-root faces
  bias the IRLS centres, so the cap per-feature tilt read 1.46° against 0.13° from a lever-excluded
  cone fit. On the 3.25 mm span of the helical sleeve, per-feature tilt is unreliable.
- **D4** `stl-re-orchestrate/scripts/init_run.py:359-362`: `status` reports "scan-only needs a
  MEASUREMENTS decision" even though DECISIONS.md has one; it never reads DECISIONS.md.
- **D5** `stl-re-intake-datum/scripts/datum_fit.py:487`: `noise --circle-z` needs a closed loop.
  On the holed chrome neck no z worked, so I used the cap-mouth ring at z 14.0.
- **D6** Rebuild skill: there is no thread or helix guidance. `references/strategy-catalogue.md:123`
  lists "sweeps along 3D paths" among the HALT classes. Separately,
  `scripts/face_stats.py:180` labels helicoid sweep faces `ruled_like` with a "find the loft"
  note: a false positive for helical sweeps. I declared it in the plan.
- **D7** Known from OD-H22: the negative-vector CLI needs `--arg=-x,...`; I used that form.

## it2 (REVISE, route geometry; it1 in `_it1_SUPERSEDED/`)
- Finding: the 0.005 mm tessellation was not watertight at z≈15.99, r≈6.42, θ≈180°, where the rib
  foot touched the inner-groove torus along a line.
- Changes, both construction only; **params.json is unchanged**:
  - (1) F11 rib foot: `groove_in_bottom_z` → `groove_in_bottom_z − OV`. This covers all 4 ribs,
    which shared the tangent foot plane.
  - (2) F13 bottom-ramp tool floor: `zb − OV` → `zb − OV − sleeve_bottom_ramp_h`. My own 0.005 mm /
    0.1 rad check found a second non-manifold run in it1 at z = sleeve_bottom_z, θ≈193°. It was
    there in it1 but hidden at 0.05 rad. The shallow tool floor left an unintended wedge of sleeve
    material, up to ≈0.53 mm, under the ramp for θ 193°→255°.
- Result: 1 valid closed solid in both frames, **83 faces** (it1 88), volume **11,655.64 mm³** (it1
  11,657.12). Fillets 4 OK. B-spline faces 9, all on the ramps.
- **Watertight:** each STEP was tessellated at 0.003/0.005/0.01 mm × 0.1/0.05 rad. trimesh
  `is_watertight` is True with 0 non-manifold and 0 open edges, in both frames. `_cad.stl` is
  watertight too.
- Self-check (NOT QA): scan→CAD p95 0.178 / max 2.302, unchanged (the max is the hole-B artefact).
  CAD→scan raw p95 0.455.
- Script/verify note: at 0.005 mm the verifier's probe evidently used the finer angular deflection
  (0.05 rad), and at that setting the F13 defect does not show. A probe should sweep the angular
  deflection too.

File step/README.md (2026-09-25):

# step/

Clean parametric STEP (AP214, mm) per part: `OD-Xnn_<short_name>.step` (see [PART_NUMBERING](../docs/PART_NUMBERING.md)). Rebuilt from `scans/` + caliper data — never raw-mesh exports.

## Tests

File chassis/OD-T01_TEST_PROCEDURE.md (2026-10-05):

# OD-T01 — group head bench pressure test

The test closes OD-G01 REQ-12: the printed housing carries the brew load
(15 bar on a Ø51 basket, 3.06 kN) through its lugs, body and inserts as it does
in the machine. The rig is `OD-T01_pressure_test_rig` (PLA, Kobra Max 3, lying
on its rear face, no supports, 240 × 160 × 120). Every value below is an assumption from the
spec's §6 (`reports/OD-T01_pressure_test_rig/00_Spec/DESIGN_SPEC.md`) until the
bench confirms it.

> **Rig v02 (25 mm plate).** Review RV01 found the v01 plate (15 mm) only about
> 1.5 times as strong as the load through the hub window; the Usta chose v02. The
> v02 plate runs at about 9.6 MPa at 15 bar, a factor of about 4 against an unsourced
> 40 MPa for printed PLA, and each screw head bears on 5.0 of plate. Review RV02
> flags the **head bearing**: 765 N per screw on the ISO 7380 head's ring (16.4 mm²)
> is about 47 MPa, near printed PLA's compressive yield. So:
> - print the rig with **100 % infill** (or at least the plate solid round the four
>   counterbores); the factor above assumes a solid plate;
> - if you have a Ø7.5 flat-bottomed cutter, open the four counterbores to Ø7.5
>   and put an **M3 steel washer (ISO 7089, Ø7)** under each head (about 25 MPa);
> - in any case watch the heads at each step: a head sinking into the plate is a
>   stop.

## Parts (bought, A-04 / A-06 / A-11)

| Part | Note |
|---|---|
| Hand hydrostatic test pump, or the Ulka pump OD-H01 with its OPV | cold tap water only (A-03) |
| Pressure gauge 0–25 bar | readable from behind the shield |
| Bleed valve and tee | at the top of the line, to purge air |
| PTFE or reinforced tube, rated ≥ 25 bar | to the OEM water connection |
| OEM water connection OD-G07 gasket, OD-H14, OD-H15 | seats on OD-G04's hub tube through the window (A-05) |
| Stainless 51 mm blind basket | in OD-G10; closes the mouth (A-06) |
| 4 × M3 × 10 ISO 7380 (+ 4 × M3 washers ISO 7089, optional) | rig plate into the housing's inserts (5.0 of plate under the head, 5.0 into the 5.7 insert) |
| 4 × M4 or 4 mm wood screws, or 2 clamps | base wings to the bench (A-11) |
| Clear shield (polycarbonate sheet) and safety glasses | between you and the rig |
| Shallow tray ≤ 50 tall | under the portafilter on the base (A-07) |

## Steps

1. Screw the rig to the bench. Set the housing (with its inserts and OD-G04) on
   the plate's underside and drive the four M3 × 10 from above (a 2 mm hex key reaches down the 20 deep counterbores); snug, do not crush.
2. Fit the water connection on the hub tube through the window and run the line
   pump → tee with bleed → gauge → connection.
3. Put the blind basket in the portafilter, insert it turned about −50°, lift
   and lock it. Note the handle angle at lock (A-07).
4. Fill with the bleed open until water runs without air, then close the bleed.
5. Behind the shield, raise the pressure in steps of **3, 6, 9, 12, 15 bar**,
   holding each for **60 s**. At each step, watch the gauge and look at:
   the housing's lugs and body; the inserts; the rig's plate between the screw
   lines beside the hub window (F1); the counterbore floors under the screw heads.
6. At 15 bar hold **5 min**.
7. Release through the bleed, unlock, and inspect the housing and the rig.

**Stop at once** on any of: a step drop on the gauge, a crack or whitening on
the housing or the rig, a weep at the lugs or inserts, a screw head pulling
into the plate, or the plate visibly bowing.

## Pass (A-03)

The housing holds 15 bar for 5 min with no crack, no step in the gauge and no
weep at the lugs. The rig passes REQ-08 when it shows no visible yield or crack.

## Record

Date, rig version (v02), filament, infill and print settings; washers or not; handle angle at
lock; for each step the gauge reading at start and end of the hold and what was
seen; the highest pressure held; photos of the lugs, the inserts and the rig's
plate before and after. Add the result to
`reports/OD-G01_group_head_housing/` (REQ-12) and
`reports/OD-T01_pressure_test_rig/` (REQ-08, A-02 … A-08, A-11).

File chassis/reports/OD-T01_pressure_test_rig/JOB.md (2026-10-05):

---
schema: oguz-job-v1
job_id: "20261002-od-t01-pressure-test-rig"
code: ODT01
milestone: M1
title: "Open Dedica OD-T01 group head bench pressure-test rig"
lane: CAD
state: J5_DELIVER
blocked_on: null
next_action: "J5: the Usta merges the open-dedica PR; then J6 close with PHYSICAL_OUTCOME pending the bench test (REQ-08, OD-G01 REQ-12)"
data_class: PUBLIC
size: S
process: [FDM]
gate_sections: [U, D, J]
spec: "00_Spec/DESIGN_SPEC.md"
spec_version: "1.3"
workspace: "${OGUZ_JOBS}/20261002-od-t01-pressure-test-rig"
delivery: "${OGUZ_DELIVERY}/20261002-od-t01-pressure-test-rig"
artifacts: "${OGUZ_ARTIFACTS}/20261002-od-t01-pressure-test-rig"
repo_commit: "10929db1408d89144bd4af9cad971440427933d0"
active_target: od_t01_rig_v02
revision: A
open_assumptions: [A-01, A-02, A-03, A-04, A-05, A-06, A-07, A-08, A-09, A-10, A-11, A-12]
attempts: {build: 2, export: 0, tool: 0}
caps: {build: 2, export: 2, tool: 2, fix_cycles: 3}
reviews:
  - {id: RV01, target: od_t01_rig_v01, verdict: APPROVED_ASSUMPTION_CONDITIONAL, blockers: 0, date: "2026-10-03"}
  - {id: RV02, target: od_t01_rig_v02, verdict: APPROVED_ASSUMPTION_CONDITIONAL, blockers: 0, date: "2026-10-03"}
usta_gates:
  - {gate: spec_ratified, outcome: "1.0", date: "2026-10-02"}
  - {gate: concept_picked, outcome: C1, date: "2026-10-02"}
  - {gate: spec_ratified, outcome: "1.1", date: "2026-10-02"}
  - {gate: spec_ratified, outcome: "1.2", date: "2026-10-03"}
  - {gate: question_answered, outcome: v02_25mm_plate, date: "2026-10-03"}
  - {gate: spec_ratified, outcome: "1.3", date: "2026-10-03"}
deliverables: [STEP, STL, "3MF", scripts, REPORT]
physical_outcome: n/a
client_source_delete_after: null
---

<!--
JOB.md is the job's state and its resume point (PLAYBOOK §5). Only
tools/jobstate.py writes it (D-032), at the end of every orchestrator turn. Keep the
whole file under 5,000 tokens so it survives compaction whole: no narrative, no
logs, no measurements (those live in REPORT, VERDICT, and EVENTS.jsonl).

The SessionStart hook prints job_id, code, lane, data_class, state, blocked_on,
active_target, attempts against caps, next_action, open_assumptions, and the notes
section below.

Counters: build counts the designer packages sent for the active target (in the RE
lane, the re-drafter packages for the active feature), a RETURNED submission
included; export and tool count retries in the current step. Counters reset only
when a new target or RE feature starts, or when the Usta orders another round.
Reaching a cap is a halt (PLAYBOOK rule 9). fix_cycles goes into the designer's brief
and bounds its own fix-and-re-measure loop.
-->

## Notes for a resuming session

## Close summary

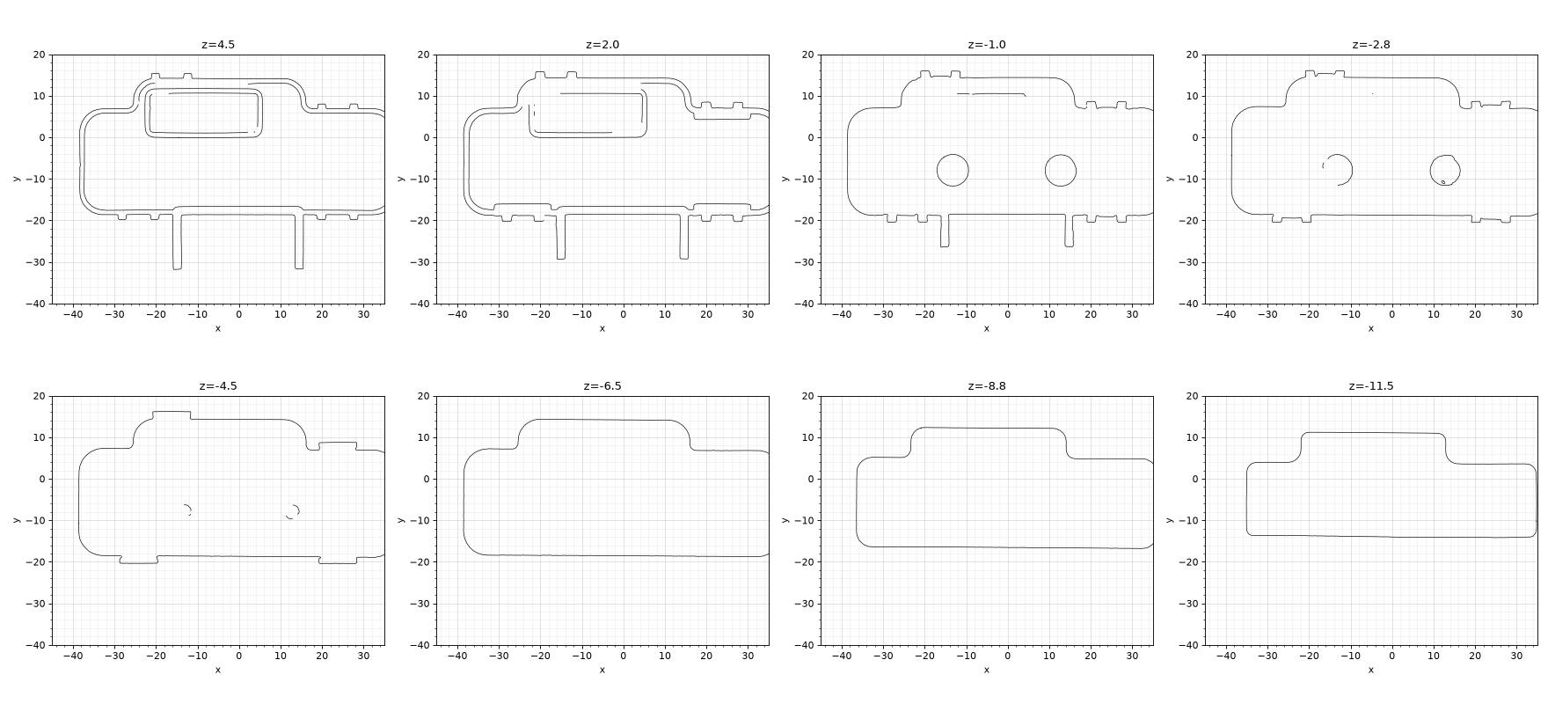
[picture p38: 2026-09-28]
step/reports/OD-E02_control_board/source/measure/figures/al_z1.png

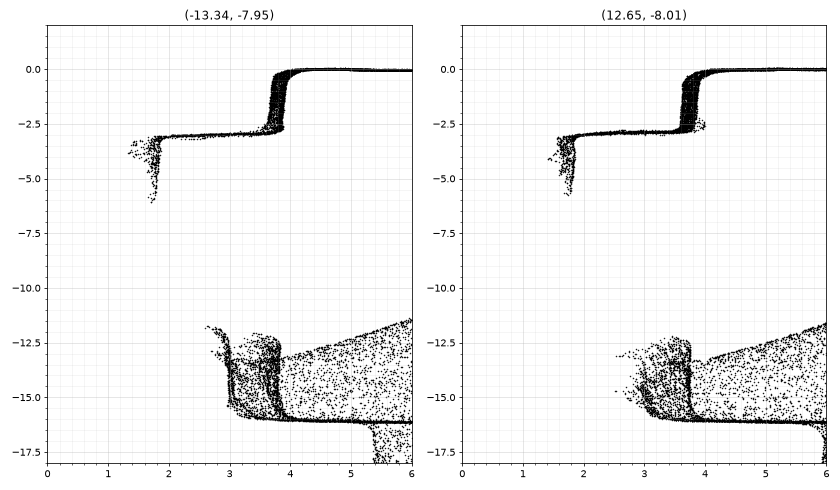
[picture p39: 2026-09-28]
step/reports/OD-E02_control_board/source/measure/figures/rz_holes.png

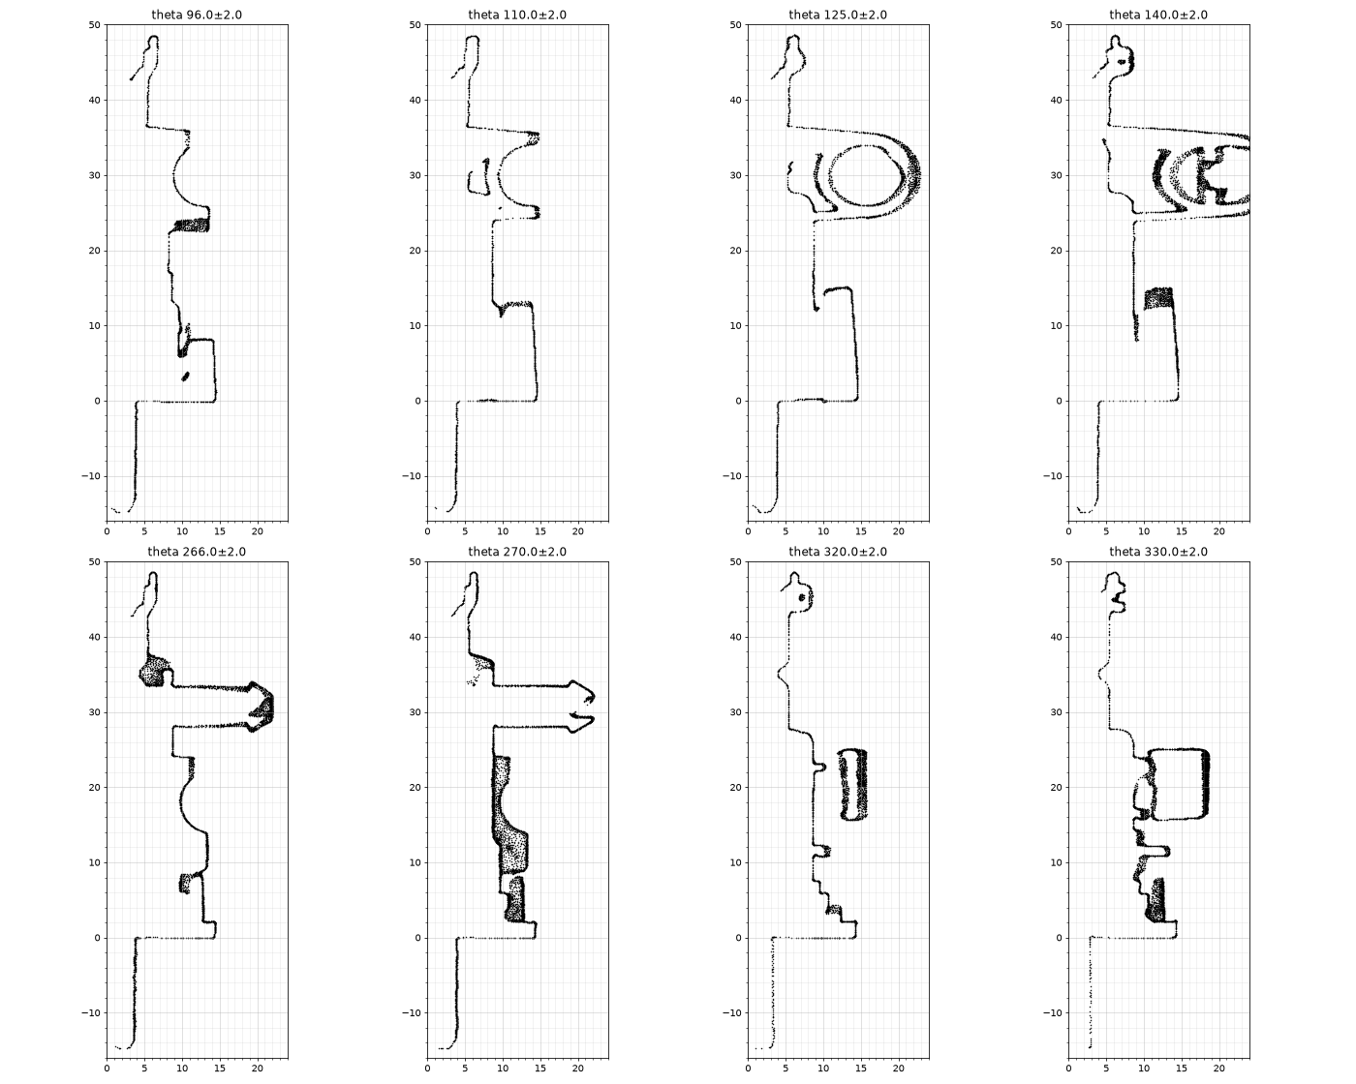
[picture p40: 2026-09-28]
step/reports/OD-S01_steam_valve/source/measure/figures/rz_b.png

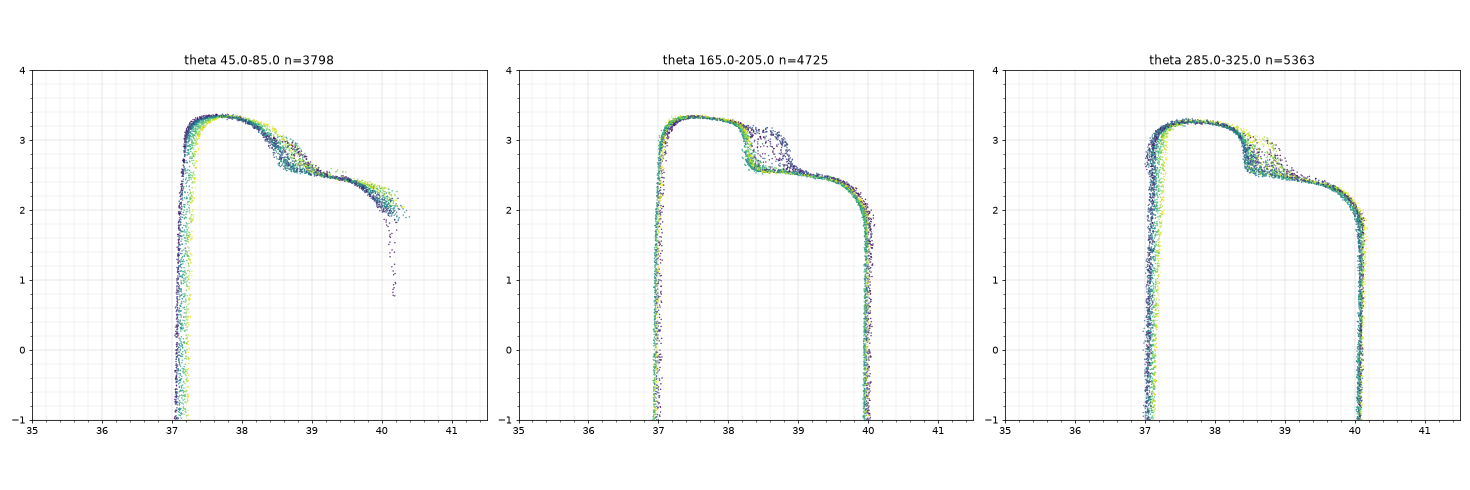
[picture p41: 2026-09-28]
step/reports/OD-G09_group_head_bayonet_cup/source/measure/figures/prof_rim.png

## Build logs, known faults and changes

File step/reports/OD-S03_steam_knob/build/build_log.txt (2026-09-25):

build123d 0.13.0  params=measure/params.json  (self-built model; any check here is a self-check, not QA)
F01 cap cylinder R12.5298 z 0.0000..13.6892 at (0.0320,-0.0951)
F02 lever: tip centre (22.6482,0.0508) tangent R4.4367 (derived from flank lines), tip x max 27.0849 at z0
F03 cap+lever union: solids=1 faces=6
F04 lever-cap blend +Y fillet target R6.10451 used R6.10451 on 1 edges OK
F04 lever-cap blend -Y fillet target R7.01465 used R7.01465 on 1 edges OK
F05 draft 3.0062 deg on 6 side faces; cap top-circle radius at the step face 13.2487 (expected R0+H tan = 13.2487); valid=True
F06 crown round fillet target R2.45906 used R2.45906 on 6 edges OK
F07 step-face edge round fillet target R0.534362 used R0.534362 on 6 edges OK
F08 pocket tool: 6 side faces drafted 3.9860 deg about z=13.6892; floor z 8.5350; valid=True
F08 pocket cut: solids=1 faces=27
F09 collar revolve: groove 10.141->8.823 bottom 16.278; join r 7.804; valid=True
F10 stem revolve at (-0.1840,0.1127) [line at z=22.900]; valid=True
F11 rib theta -0.903: width 1.073, tip r 6.634@17.07 -> 6.277@28.309, foot z 15.490 (groove bottom - OV)
F11 rib theta 90.733: width 0.916, tip r 6.376@17.07 -> 5.842@28.211, foot z 15.490 (groove bottom - OV)
F11 rib theta 179.402: width 1.244, tip r 6.481@17.07 -> 6.480@28.243, foot z 15.490 (groove bottom - OV)
F11 rib theta -90.389: width 1.022, tip r 6.526@17.07 -> 6.320@28.171, foot z 15.490 (groove bottom - OV)
F12 spigot revolve at (-0.0577,0.0563) [line at z=33.408]: 4 crests [32.945, 34.176, 35.407, 36.638], bottom round R0.6381 (derived c1-zb), top round R0.5791 (derived zt-c_n), cusp r 5.7712; valid=True
F13 bottom ramp cut: rise 1.0591 over 132.65->255.39 deg; tool valid=True; spigot solids=1 valid=True
F14 top tail union: rise 0.9076 over 124.62->245.43 deg; tool valid=True; spigot solids=1 valid=True
F15a +collar: solids=1
F15b +stem: solids=1
F15c +ribs: solids=1
F15d +spigot: solids=1
F15 union+clean: solids=1 faces=83 valid=True volume=11655.642
all params used

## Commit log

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2026-09-25 Part numbering (OD-Xnn, letter groups) + CSV-driven master BOM (#11)
    * Add OD-NNN part numbering and CSV-driven master BOM
    Every part (OEM spares, printed chassis parts, hardware, assemblies,
    fixtures) now has a project part number used for CAD, scan folders and
    issues. docs/bom.csv is the source of truth; tools/build_bom.py renders
    docs/BOM.md and CI checks they stay in sync. Also fixes the control board
    OEM code (ref 15 is 7313285189; 7313285179 is the upper cover).
    * Use group letters in part numbers (OD-H11 instead of OD-111)
    H hydraulic, G group head, W water, E electronics, C chassis,
    F fasteners/hardware, S steam, R reference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
    [bom.csv]
2026-09-25 Add raw scans: OD-H11 thermoblock and OD-H01 ULKA pump (#12)
    CR-Scan Raptor laser scans exported as binary STL (mm) with previews,
    README (method, defects, what's missing) and caliper sheet stubs.
    OD-H01 marked scanned in the BOM.
    [bom.csv]
2026-09-25 Add OD-H01 ULKA pump STEP (scan rebuild) with RE report (#14)
    Parametric build123d rebuild of the pump scan: datum-frame STEP for CAD
    plus a scan-frame copy, deviation-gate report, parameters and scripts.
    Product/solid names set to OD-H01; BOM status -> modeled.
    [OD-H01_ulka_ep5_pump.step, OD-H01_ulka_ep5_pump_scanframe.step, bom.csv]
2026-09-25 Add OD-H11 thermoblock STEP (feature-based scan rebuild) with RE report (#16)
    Datum-frame STEP for CAD plus scan-frame copy, 406-face single solid,
    deviation report, parameters and feature-tree scripts. Product/solid
    names set to OD-H11; BOM status -> modeled. Deprecated v1 banded model
    and NX files are not included.
    [OD-H11_thermoblock.step, OD-H11_thermoblock_scanframe.step, bom.csv]
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2026-09-25 Add scan → STEP progress board generated from bom.csv (#18)
    tools/build_progress.py renders docs/img/step_progress.svg from the
    status of every CAD=SCAN part; CI checks it is up to date. New
    docs/STEP_PROGRESS.md with WIP renders (OD-H01, OD-H11, OD-H24).
    OD-H24 flowmeter marked scanned (STEP rebuild in progress).
    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
    [bom.csv]
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2026-09-25 Add OD-H24 flowmeter scan + STEP, refresh showcase image (#22)
    Raw CR-Scan Raptor mesh (scans/OD-H24_flowmeter) plus feature-based
    build123d rebuild: flat single-product datum STEP for CAD, scan-frame
    copy, deviation report, parameters and measurement scripts. Product/solid
    names set to OD-H24; BOM status -> modeled.
    [OD-H24_flowmeter.step, OD-H24_flowmeter_scanframe.step, bom.csv]
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2026-09-25 Add OD-H24 flowmeter raw scan and STEP rebuild with RE report (#21)
    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
    [OD-H24_flowmeter_scanframe.step]
2026-09-25 Add donor-parts BOM annotation; new OD-S06 steam valve bracket (#24)
    Annotated photo of the parts on the scan turntable with their OD
    numbers (docs/img/donor_parts_bom.png, shown in STEP_PROGRESS.md).
    Adds OD-S06 steam valve bracket to the BOM (phase 2, deferred).
    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
    [bom.csv]
2026-09-25 Add OD-H22 3-way valve raw scan, photos and STEP rebuild (#26)
    Raw CR-Scan Raptor mesh + 4 photos (scans/OD-H22_3way_valve), datum-frame
    STEP renamed to OD-H22, and the full staged RE run (intake, measure,
    build, independent QA verdict, owner acceptance, delivery report) under
    step/reports/OD-H22_3way_valve. BOM status -> modeled; progress page
    updated.
    Also re-removes step/OD-H24_flowmeter_scanframe.step (deleted on main,
    accidentally restored by #21) and replaces scan-frame links in the
    report READMEs with the transform to use instead.
    [OD-H22_3way_valve.step, OD-H24_flowmeter_scanframe.step, bom.csv]
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2026-09-25 Add OD-G04 brewing gasket support scan and STEP; drop catalogue photos (#30)
    Raw CR-Scan Raptor mesh (scans/OD-G04_brewing_gasket_support), datum-frame
    STEP renamed to OD-G04, and the staged RE run (intake, measure, build,
    independent QA verdict, owner acceptance, delivery) under step/reports.
    BOM: OD-G04 cad CALIPER -> SCAN, status -> modeled; progress page updated.
    The run's four reference photos are seller catalogue images and are not
    included; deviation arrays (.npz) and meshes are not copied.
    Also removes OD-H22 photos 1-3, which were seller catalogue images
    (one watermarked) published by mistake in #26; only the own photo_4 stays.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
    [OD-G04_brewing_gasket_support.step, bom.csv]
2026-09-25 Add OD-S03 steam knob raw scan and STEP rebuild (#32)
    Raw CR-Scan Raptor mesh (scans/OD-S03_steam_knob), datum-frame STEP
    renamed to OD-S03, and the staged RE run (iteration 2: intake, measure,
    build, independent QA verdict, owner acceptance, delivery) under
    step/reports. BOM: OD-S03 cad CALIPER -> SCAN, status deferred -> modeled;
    progress page updated. Not included: catalogue photos, meshes,
    dev_arrays.npz, superseded iteration 1, private skill_scripts helpers.
    [OD-S03_steam_knob.step, OD-S03_steam_knob_raw.stl, bom.csv]
2026-09-28 Add 7 scan-to-STEP deliveries from 2026-09-28 (#40)
    Raw scans, datum-frame STEPs (product/solid named with the OD code) and
    RE reports for:
    - OD-E01 Power PCB, OD-E02 Control button board
    - OD-S01 Steam valve assembly, OD-S02 Steam wand (hose assembly + nozzle)
    - OD-W03 Tray gasket (water tank seat)
    - OD-G09 OEM group head bayonet cup (new BOM row, reference for OD-G01)
    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
    [OD-E01_power_pcb.step, OD-E01_power_pcb_raw.stl, OD-E02_control_board.step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]
2026-09-28 Add OD-H21 anti-drip valve raw scan and STEP rebuild (#42)
    Raw CR-Scan Raptor mesh (scans/OD-H21_antidrip_valve), datum-frame STEP
    named OD-H21, and the RE run report (deliverables + source) under
    step/reports. BOM status -> modeled, issue #41; progress page updated.
    Catalogue photos, meshes, NX files and files > 5 MB are left out.
    [OD-H21_antidrip_valve.step, bom.csv]
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2026-09-30 chassis: OD-G01 build v01 record and spec 1.2 for round 2
    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
    [od_g01_assembly_C1_v01.step, od_g01_housing_C1_v01.step, od_g01_housing_C1_v01.stl]
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2026-09-30 chassis: add the OD-C07 job record at J2 (spec 1.0, intake, briefs)
    Claude-Session: https://claude.ai/code/session_01FujqgPbr1oihHaNnj8ygB6
    [bom_rows.csv]
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2026-09-30 chassis: OD-C03 plan, spec 1.1 and build v01 record; OD-C04 at J2
    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
    [od_c03_assembly_C1_v01.step, od_c03_cradle_C1_v01.step, od_c03_cradle_C1_v01.stl]
2026-09-30 chassis: OD-C04 plan, spec 1.1 and build brief; OD-C03 at J4 review
    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
    [remesh_tol0p01.stl]
2026-09-30 chassis: OD-C03 review RV01, REVISE round to spec 1.2, build v02 brief
    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
    [M04_hole_filled.step, coarse_tol0p1.stl, holed.stl]
2026-09-30 chassis: OD-C04 spec 1.2 makes the heat bench gate Soft before review
    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
    [od_c04_assembly_C1_v01.step, od_c04_mount_C1_v01.step, od_c04_mount_C1_v01.stl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]
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2026-09-30 chassis: OD-C04 thermoblock mount approved (assumption-conditional), STEP, STL, 3MF and scripts
    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
    [OD-C04_thermoblock_mount.3mf, OD-C04_thermoblock_mount.step, OD-C04_thermoblock_mount.stl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]
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2026-09-30 chassis: OD-C03 pump cradle approved (assumption-conditional), STEP, STL, 3MF and scripts
    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
    [OD-C03_pump_cradle.3mf, OD-C03_pump_cradle.step, OD-C03_pump_cradle.stl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]
2026-09-30 docs: mark OD-C03 and OD-C04 modeled, add their hardware and OD-C01 insert interfaces
    Claude-Session: https://claude.ai/code/session_01McFPDZpLpGKhuUDZb91Nwj
    [bom.csv]
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2026-09-30 chassis: OD-C03 pump cradle and OD-C04 thermoblock mount, designed and reviewed (#43)
    * chassis: open the OD-C03 and OD-C04 job records (intake, spec 1.0, J2 briefs)
    * chassis: OD-C03 plan, spec 1.1 and build v01 record; OD-C04 at J2
    * chassis: OD-C04 plan, spec 1.1 and build brief; OD-C03 at J4 review
    * c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
    [M04_hole_filled.step, OD-C03_pump_cradle.3mf, OD-C03_pump_cradle.step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]
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2026-09-30 chassis: OD-C01 spec 1.0 with the machine layout; OD-C05 plan and spec 1.1
    OD-C01: intake report, DESIGN_SPEC 1.0 (plate 240 x 6 x 405, the joints of
    OD-C03, OD-C04 and OD-C05, the bulkhead line, reserved zones, sixteen insert
    holes, feet and drain holes) and the J2 designer brief.
    OD-C05: the J2 plan with its probes, which found two spec conflicts (a 1.92
    web at the top counterbores, hole crowns against D-03a); DESIGN_SPEC 1.1
    resolves them (R 6 corners about the top holes, named exception extended to
    D-03a) and raises the group head axis to 175 from the OD-C01 layout; the J3
    designer brief.
    Claude-Session: https://claude.ai/code/se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
2026-09-30 chassis: note the group-head orientation correction in the OD-G01 record
    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
2026-09-30 chassis: OD-C05 v03 stopped on two spec drawing errors; spec 2.2, halt recorded, v04 brief
    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
    [od_c02_assembly_C1_v01.step, od_c02_bulkhead_C1_v01.step, od_c02_bulkhead_C1_v01.stl]
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2026-10-03 chassis: deliver OD-C09 front panel v01 and OD-T01 rig v02
    OD-C09: the reviewed v01 (RV01 approved on assumptions) with STEP, STL,
    3MF and build scripts. OD-T01: v02 with the 25 mm plate replaces v01
    (RV02 approved on assumptions); the test procedure covers the v02 head
    bearing finding.
    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
    [OD-C09_front_panel.3mf, OD-C09_front_panel.step, OD-C09_front_panel.stl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]
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
